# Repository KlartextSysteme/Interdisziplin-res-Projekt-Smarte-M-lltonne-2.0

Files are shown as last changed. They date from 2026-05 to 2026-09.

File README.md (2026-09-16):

# Intelligente Entsorgungssysteme: Smarte Mülltonne 2.0

Software-Repository zum Interdisziplinären Projekt (Prüfungsnummer 2220) im Masterstudiengang Digitale Technologien der Fachhochschule Südwestfalen, Sommersemester 2026.

Team: Alaeddine Baghyour, Jan-Lukas Bellenhaus, S. Fulya Bulut, Theresa Pelz, Jonas Wiesner. Hinweis zur Commit-Historie: Die Commits unter dem Konto Klartext-Systeme stammen von Jonas Wiesner und Jan-Lukas Bellenhaus, die über dasselbe Konto gearbeitet haben. Eine Aufteilung der Beiträge nach Personen ist aus der Historie deshalb nicht ablesbar.

## Was das System tut

Die Smarte Mülltonne fährt selbstständig entlang einer Bodenlinie von ihrem Stellplatz zur Straße und zurück. Ein Raspberry Pi Pico W steuert dabei zwei Schrittmotoren, liest fünf Liniensensoren und mehrere Ultraschallsensoren über einen Multiplexer und misst Füllstand und Akkuspannung. Ein Touchdisplay an der Tonne zeigt Zustand und Diagnosewerte und nimmt lokale Befehle entgegen. Über WLAN meldet sich der Pico bei einer TCP-Bridge auf einem Laptop, die seine Telemetrie an das Backend weiterreicht und Fahrbefehle aus der Kommando-Warteschlange an den Pico zurückgibt. Das Backend (FastAPI, SQLite) verwaltet Tonnen, Füllstände, Sicherheitsereignisse und Routen und bindet einen LLM-Agenten für die Routenplanung an. Die Web-App (Next.js) ist der Leitstand: Flottenliste, Live-Karte, Chat mit dem Agenten, Energie- und Sicherheitspanel sowie Sperren und Steuern einzelner Tonnen.

## Ordnerstruktur

Der gesamte Projektinhalt liegt unter `Smarte Mülltonne/`. Alle Pfade unten sind relativ dazu. Für die Abgabe wurden zwei Ordner umbenannt, `smart-bin` heißt jetzt `Flottenmanagement` und `Test_2` heißt `Hardwaretests`; die Dokumentation verwendet die neuen Namen, siehe Abschnitt „Codeverweise in der Dokumentation". Die Semesterdokumentation und die Abschlusspräsentation sind nicht Teil dieses Repos; sie liegen im Abgabeordner. Der Vorgängerstand (Smarte Mülltonne 1.0, Ordner `Alt/`) und ein früherer Doku-Arbeitsstand wurden für die Abgabe entfernt und sind in der Git-Historie bis Commit `dae74ec9` erhalten.

| Pfad | Inhalt |
|---|---|
| `Software/Quellcode/Client/` | MicroPython-Firmware des Pico W in der Tonne: Fahrlogik, Sensorik, Touchpanel-Oberfläche, TCP-Client zur Bridge. `main.py` startet den Controller. |
| `Software/Quellcode/Client/assets/` | Vorgerenderte Bild-Assets für das Touchdisplay (WF1/RLE-Format). |
| `Software/Quellcode/Server/` | Früher TCP-Server für die Missionssteuerung auf dem Laptop; im Zielsystem übernimmt die Bridge unter `Flottenmanagement/bridge/` diese Rolle. |
| `Software/Flottenmanagement/backend/` | FastAPI-Backend mit Datenmodell, Routern, Agent und Truck-Simulator. |
| `Software/Flottenmanagement/frontend/` | Next.js-Web-App (Leitstand und Admin-Seite). |
| `Software/Flottenmanagement/bridge/` | TCP-Bridge zwischen Pico und Backend sowie ein Pico-Simulator. |
| `Software/Flottenmanagement/simulator/` | Skripte, die Füllstände, Energie, Sicherheitsereignisse und LKW-Fahrt simulieren. |
| `Software/Flottenmanagement/firmware/pico_touchpanel/` | Eigenständige Touchpanel-Firmware mit Kalibrierung, Asset-Werkzeugen und datierten Backups der Display-Stände. |
| `Software/Flottenmanagement/docs/` | Architektur, API-Vertrag, CI-Vorgaben, Handoffs, Design-Specs und Pläne aus der Entwicklung. |
| `Software/Hardwaretests/` | Einzelne Hardware-Testskripte (Motoren, Sensoren, Multiplexer, Display) aus der Inbetriebnahme. |
| `Software/Visualisierungen/` | Architektur- und Zustandsdiagramme, Pinout, Schaltpläne. |
| `Software/Übergabedokument_Smarte_Muelltonne.pdf` | Technisches Übergabedokument zum Client-Server-Quellcode des Pico (Stand April 2026). |

An der Wurzel liegen außerdem `render.yaml` (Deployment-Blueprint für Backend und Web-App auf Render) und `.gitignore`.

## Stand der Dokumentation

Die Semesterdokumentation bezieht sich auf den Branch `route-start-live-akku` im Stand des Commits `c10b40b` vom 11.07.2026. Dieser Commit ist in `main` enthalten. In diesem Stand heißen die Ordner noch `smart-bin` und `Test_2`, und die Ordner `Alt/` sowie `Dokumentation & Präsentation Neu/` sind noch vorhanden. Um genau diesen Stand zu sehen:

```
git checkout c10b40b
```

Zurück zum aktuellen Stand mit `git checkout main`.

## Codeverweise in der Dokumentation

Die Dokumentation zitiert Pfade relativ zu `Smarte Mülltonne/Software/` im Stand `c10b40b`. Nach der Umbenennung für die Abgabe gilt auf `main` die rechte Spalte. Dateien ohne Eintrag in der rechten Spalte haben sich nicht bewegt.

| Pfad in der Dokumentation (Stand `c10b40b`) | Pfad auf `main` |
|---|---|
| `Quellcode/Client/main.py` | unverändert |
| `Quellcode/Client/ui.py` | unverändert |
| `Quellcode/Client/ultraschallsensor.py` | unverändert |
| `Quellcode/Client/global_controller_test.py` | unverändert |
| `Quellcode/Client/multiplexer.py` | unverändert |
| `Quellcode/Client/display.py` | unverändert |
| `Quellcode/Client/touchpanel.py` | unverändert |
| `Quellcode/Client/wireframe.py` | unverändert |
| `Quellcode/Client/assets/` | unverändert |
| `smart-bin/backend/config.py` | `Flottenmanagement/backend/config.py` |
| `smart-bin/backend/agent/planner.py` | `Flottenmanagement/backend/agent/planner.py` |
| `smart-bin/backend/agent/tools.py` | `Flottenmanagement/backend/agent/tools.py` |
| `smart-bin/backend/routers/admin_demo.py` | `Flottenmanagement/backend/routers/admin_demo.py` |
| `smart-bin/backend/routers/bins.py` | `Flottenmanagement/backend/routers/bins.py` |
| `smart-bin/backend/routers/commands.py` | `Flottenmanagement/backend/routers/commands.py` |
| `smart-bin/backend/routers/routes.py` | `Flottenmanagement/backend/routers/routes.py` |
| `smart-bin/backend/routers/ws.py` | `Flottenmanagement/backend/routers/ws.py` |
| `smart-bin/frontend/app/admin/page.tsx` | `Flottenmanagement/frontend/app/admin/page.tsx` |
| `smart-bin/frontend/app/dashboard/components/OperatorTour.tsx` | `Flottenmanagement/frontend/app/dashboard/components/OperatorTour.tsx` |
| `smart-bin/firmware/pico_touchpanel/touch_calibrate.py` | `Flottenmanagement/firmware/pico_touchpanel/touch_calibrate.py` |
| `smart-bin/firmware/pico_touchpanel/tools/png_to_wf1.py` | `Flottenmanagement/firmware/pico_touchpanel/tools/png_to_wf1.py` |
| `smart-bin/firmware/pico_touchpanel/backups/2026-06-11_light_mode_before_icon_shape_fix/` | `Flottenmanagement/firmware/pico_touchpanel/backups/2026-06-11_light_mode_before_icon_shape_fix/` |
| `smart-bin/docs/api_contract.md` | `Flottenmanagement/docs/api_contract.md` |
| `smart-bin/docs/ci_farben_typografie.md` | `Flottenmanagement/docs/ci_farben_typografie.md` |
| `smart-bin/docs/handoff_fahrlogik_2026-06-27.md` | `Flottenmanagement/docs/handoff_fahrlogik_2026-06-27.md` |
| `smart-bin/docs/touchpanel_tonnenicon_design_notes.md` | `Flottenmanagement/docs/touchpanel_tonnenicon_design_notes.md` |
| `smart-bin/docs/superpowers/plans/2026-07-04-hardware-test-followup.md` | `Flottenmanagement/docs/superpowers/plans/2026-07-04-hardware-test-followup.md` |
| `smart-bin/docs/superpowers/specs/2026-07-04-hardware-test-followup-design.md` | `Flottenmanagement/docs/superpowers/specs/2026-07-04-hardware-test-followup-design.md` |

Die gestalterischen Vorgaben für die Web-App (Farben, Ampelfarben, Schrift, Layout) stehen in `Flottenmanagement/docs/ci_farben_typografie.md`. Die Design-Spezifikationen der Agenten-Aufträge folgen dem Namensschema `<thema>-design.md` in `Flottenmanagement/docs/`.

## Starten

Backend (Python 3.12, aus `Smarte Mülltonne/Software/Flottenmanagement/backend/`):

```
pip install -r requirements.txt
cp .env.example .env
uvicorn main:app --host 0.0.0.0 --port 8000
```

In `.env` werden Admin-Token, `GROQ_API_KEY` für den Agenten, erlaubte CORS-Origins und die Depot-Koordinaten gesetzt. Die Datenbank `smart_bin.db` wird beim ersten Start angelegt.

Web-App (Node 22, aus `Smarte Mülltonne/Software/Flottenmanagement/frontend/`):

```
npm ci
npm run dev
```

Die App läuft dann auf Port 3000 und erwartet das Backend unter `NEXT_PUBLIC_API_URL` (Standard im Deployment: `http://localhost:8000`) und den Live-Kanal unter `NEXT_PUBLIC_WS_URL` (`ws://localhost:8000/ws/live`). `npm run build` erzeugt den statischen Export nach `out/`.

Bridge zur Tonne (aus `Smarte Mülltonne/Software/Flottenmanagement/`):

```
python bridge/tcp_bridge.py --bin-id 1 --backend http://localhost:8000
```

Der Pico verbindet sich mit `BRIDGE_HOST` und `BRIDGE_PORT` (50002) aus `Quellcode/Client/config.py`. Ohne Hardware lässt sich der Pico mit `bridge/pico_tcp_simulator.py` nachstellen; die Skripte in `simulator/` erzeugen Füllstands-, Energie- und Sicherheitsdaten gegen das laufende Backend.

Pico-Firmware: Die Dateien aus `Quellcode/Client/` einschließlich `assets/` auf den Pico W kopieren; `main.py` startet beim Booten den Controller. WLAN-Zugang und Bridge-Adresse stehen in `config.py`.

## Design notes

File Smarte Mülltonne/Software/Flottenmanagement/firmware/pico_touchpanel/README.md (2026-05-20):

# Pico Touchpanel Firmware

MicroPython firmware draft for the smart-bin touch display.

## Hardware

- Raspberry Pi Pico W
- ILI9341 2.8 inch SPI display
- Target UI: landscape `320 x 240`

Known working display wiring from the first hardware test:

| Signal | Pico GPIO |
|---|---:|
| SCK | GP18 |
| MOSI | GP19 |
| CS | GP17 |
| DC | GP20 |
| RST | GP21 |

## Files

- `main.py` starts the UI.
- `display.py` contains the minimal ILI9341 drawing driver.
- `ui.py` contains the screen state machine and wireframe implementation.
- `config.py` contains pins, display rotation and backend placeholders.

## First Test

Copy all `.py` files to the Pico W and run `main.py`.

If the UI is rotated or mirrored, change `DISPLAY_ROTATION` in `config.py`.
Likely values to try: `0x28`, `0x48`, `0x88`, `0xE8`.

Touch is not connected yet in this draft. For a first screen test, call
`ui.handle_touch(x, y)` from the REPL after `main.py` has drawn the UI.

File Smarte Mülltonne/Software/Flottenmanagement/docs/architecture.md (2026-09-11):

# Smarte Mülltonne 2.0 — Architektur-Dokumentation

> **Projekt:** FH SWF Digitale Technologien, interdisziplinär
> **Software-Lead:** Jonas Wiesner (Backend, LLM-Agent, Dashboard)
> **Hardware-Lead:** Mech-Team (Antrieb, Sensorik, Tonne-Bau)
> **Stand:** Mai 2026
> **Scope:** Software-Komponenten unter `Flottenmanagement/` — Backend, Frontend, Simulatoren, Agent, Pico-W-Touchpanel-Konzept

> **Aktueller Agent-Handoff:** siehe `docs/handoff_2026-06-12.md` fuer den
> neuesten Stand nach Render-Deployment, Groq-Umstellung, Solar-Entfernung aus
> der UI und die bekannte Truck-Depot-Routing-Baustelle.

---

## 1. System-Überblick

Die Smarte Mülltonne 2.0 ist ein Hardware-/Software-Verbundsystem aus autonomen Mülltonnen, einem Sammelfahrzeug und einer zentralen Flottenmanagement-Plattform. Diese Doku beschreibt ausschließlich die **Software-Schicht**. Die Mechanik (Antrieb, Fahrwerk, Sensor-Integration) wird parallel vom Mech-Team gebaut und ist hier nur als API-Schnittstelle relevant.

### 1.1 Komponenten-Diagramm

```
┌──────────────────────────────────────────────────────────────────────────┐
│                          Smarte Mülltonne 2.0                            │
│                                                                          │
│  ┌─────────────────┐    HTTP / SSE    ┌──────────────────────────────┐  │
│  │   Frontend      │ ←─────────────→  │  Backend (FastAPI)           │  │
│  │   (Next.js 15)  │   WebSocket      │                              │  │
│  │                 │ ←─────────────→  │  ┌─────────┐  ┌──────────┐   │  │
│  │  • Dashboard    │                  │  │ SQLite  │  │ Routing  │   │  │
│  │  • Map (Leaflet)│                  │  │  (DB)   │  │ (OSRM)   │   │  │
│  │  • Chat (SSE)   │                  │  └─────────┘  └──────────┘   │  │
│  │  • Sim-Controls │                  │                              │  │
│  └─────────────────┘                  │  ┌──────────────────────┐    │  │
│                                       │  │ LangChain Agent      │    │  │
│                                       │  │  ↳ Groq Llama 3.3    │    │  │
│                                       │  └──────────────────────┘    │  │
│                                       └────────┬─────────────────────┘  │
│                                                │                        │
│                            HTTP polling (2s)   │                        │
│                  ┌─────────────────────────────┼──────────────────────┐ │
│                  ▼                             ▼                      ▼ │
│         ┌────────────────┐         ┌────────────────┐      ┌──────────┐ │
│         │  mock_truck    │         │  mock_bins     │      │ Pico W   │ │
│         │  (Python sim)  │         │  (Python sim)  │      │ Tonne(n) │ │
│         │                │         │                │      │ (geplant)│ │
│         └────────────────┘         └────────────────┘      └──────────┘ │
└──────────────────────────────────────────────────────────────────────────┘
```

### 1.2 Tech-Stack

| Schicht | Technologie | Begründung |
|---|---|---|
| Frontend | Next.js 15 (App Router) + React 19 + TypeScript + Tailwind v4 | SSR-fähig, moderne Hooks, kleines Setup für Single-Page-Dashboard |
| Karten | Leaflet + react-leaflet 5 + OpenStreetMap-Tiles | Kein API-Key, freie Karten |
| Backend | FastAPI + Pydantic + SQLAlchemy 2.0 | Async-first, OpenAPI auto-doc, gute DX |
| Datenbank | SQLite | Single-Node-Demo, kein Server, später durch Postgres tauschbar (URL-Tausch) |
| Routing | OSRM Public Demo + python-tsp | Echte Straßen-Routen, Open-Source-TSP-Heuristiken |
| Agent | LangChain 1.x + LangGraph + Groq (Llama 3.3 70B) | Tool-Calling, Free-Tier ausreichend für Demo |
| Realtime | FastAPI WebSocket (Live-Daten) + SSE (Chat-Stream) | Bidirektional für Telemetrie, unidirektional für Token-Streaming |
| Tonne-Hardware | Raspberry Pi Pico W + ILI9341 + XPT2046 | MicroPython, WLAN nativ, günstig, ausreichende Performance für UI |

---

## 2. Repo-Struktur

```
Flottenmanagement/
├── backend/
│   ├── main.py                  # FastAPI-Entry, Router-Registrierung, CORS
│   ├── config.py                # Pydantic-Settings (.env-Loader)
│   ├── database.py              # SQLAlchemy-Engine + Seed-Daten (35 Tonnen)
│   ├── models/
│   │   ├── bin.py               # Bin-ORM
│   │   ├── route.py             # Route-ORM (waypoints, geometry, distances)
│   │   ├── event.py             # SecurityEvent-ORM
│   │   └── command.py           # Command-Queue für Hardware
│   ├── routers/
│   │   ├── bins.py              # GET /bins, POST /bins/{id}/update
│   │   ├── routes.py            # POST /routes/plan (NN + 2-opt + Held-Karp)
│   │   ├── security.py          # Events, lock/unlock
│   │   ├── energy.py            # Akku- und Solar-Status
│   │   ├── truck.py             # Truck-Position + -Command-Endpoints
│   │   ├── commands.py          # Pull-Queue für Hardware (Pico W)
│   │   ├── agent.py             # POST /agent/chat (SSE)
│   │   ├── sim.py               # GET/PUT /sim/speed (Speed + Pause)
│   │   └── ws.py                # WebSocket /ws/live
│   ├── services/
│   │   └── routing.py           # OSRM-Client (echte Straßen-Geometrie)
│   ├── agent/
│   │   ├── planner.py           # ChatGroq + create_agent (LangGraph)
│   │   ├── prompts.py           # System-Prompt für den Disponenten-Agent
│   │   └── tools.py             # Tool-Definitionen (9 Tools)
│   └── scripts/
│       ├── geocode_bins.py      # Nominatim-Batch-Geocoder
│       └── tsp_benchmark.py     # NN vs 2-opt vs Held-Karp
│
├── frontend/
│   ├── app/dashboard/
│   │   ├── page.tsx             # Hauptseite: Header + 3-Spalten-Layout
│   │   └── components/
│   │       ├── LeafletMap.tsx   # Karte mit AnimatedTruckMarker
│   │       ├── FleetPanel.tsx   # Linke Spalte: Tonnen-Liste
│   │       ├── ChatInterface.tsx# Rechte Spalte: SSE-Stream + Tool-Cards
│   │       ├── EnergyPanel.tsx
│   │       ├── SecurityPanel.tsx
│   │       └── AlertBanner.tsx
│   ├── lib/
│   │   ├── api.ts               # REST-Wrapper + streamChat (SSE)
│   │   └── useWebSocket.ts      # Live-Data-Hook
│   └── types/index.ts           # Bin, Route, ChatMessage, ToolCall, ...
│
├── simulator/
│   ├── mock_truck.py            # Fahrt entlang OSRM-Geometrie
│   ├── mock_bins.py             # Füllstand-Drift
│   ├── mock_energy.py           # Solar/Akku-Simulation
│   └── mock_security.py         # Sicherheitsereignisse
│
└── docs/
    ├── architecture.md          # ← dieses Dokument
    └── api_contract.md          # API-Vertrag für Pico-W-Firmware
```

---

## 3. Datenmodell

### 3.1 Bin (Mülltonne)

| Feld | Typ | Beschreibung |
|---|---|---|
| `id` | int (PK) | Eindeutige ID |
| `name` | str | Anzeigename („Westfalenweg 3") |
| `address` | str | Vollständige Adresse |
| `lat` / `lng` | float | Koordinaten (Nominatim geocodiert) |
| `fill_level` | int (0–100) | Aktueller Füllstand in Prozent |
| `battery` | int (0–100) | Akkustand |
| `solar_output_w` | float | Solar-Leistung in Watt |
| `is_charging` | bool | Lädt aktuell? |
| `status` | str | `idle` / `in_use` / `emptied` |
| `locked` | bool | Aus Sicherheits-/Wartungsgründen gesperrt |
| `last_seen` | datetime | Letzter Status-Update |

### 3.2 Route

| Feld | Typ | Beschreibung |
|---|---|---|
| `id` | int (PK) | Eindeutige ID |
| `created_at` | datetime | Plan-Zeitpunkt |
| `waypoints` | list[int] | Bin-IDs in der finalen 2-opt-Reihenfolge |
| `distance_m` | int | OSRM-Strecke (echte Straßen) |
| `duration_s` | int? | OSRM-Fahrzeit |
| `geometry` | dict | GeoJSON LineString der Tour |
| `nn_distance_m` | int? | NN-Baseline (planar, für A/B) |
| `optimized_distance_m` | int? | 2-opt-Distanz (planar) |
| `exact_distance_m` | int? | Held-Karp-Optimum (planar, nur n ≤ 15) |
| `completed` | bool | Tour abgeschlossen? |
| `llm_reasoning` | str? | Optional: Agent-Begründung |

### 3.3 SecurityEvent

| Feld | Typ | Beschreibung |
|---|---|---|
| `id`, `bin_id`, `created_at` | – | Standard |
| `event_type` | str | `tamper`, `vandalism`, `user_report`, `fire`, ... |
| `reason` | str? | Freitext-Beschreibung |
| `resolved` | bool | Quittiert? |

### 3.4 Command (Hardware-Queue)

| Feld | Typ | Beschreibung |
|---|---|---|
| `id`, `bin_id`, `created_at` | – | Standard |
| `action` | str | `lock`, `unlock`, `open_lid`, `beep` |
| `payload` | dict? | Optionale Parameter |
| `acked` | bool | Von der Hardware bestätigt? |

**Sync-Pattern:** Hardware pollt `GET /bins/{id}/pending-command` alle 2 s, führt aus, sendet `POST /bins/{id}/ack`.

---

## 4. API-Endpoints

| Methode | Pfad | Zweck |
|---|---|---|
| GET | `/health` | Healthcheck |
| GET | `/config/public` | Depot-Koordinaten, App-Konstanten |
| GET | `/bins` | Alle Tonnen |
| POST | `/bins/{id}/update` | Sensor-Update (fill, battery, status) |
| POST | `/bins/{id}/command` | Befehl in Hardware-Queue legen |
| GET | `/bins/{id}/pending-command` | Pull-Endpoint für Pico |
| POST | `/bins/{id}/ack` | Command-Ack vom Pico |
| POST | `/routes/plan` | Route planen (NN + 2-opt + Held-Karp ≤ 15) |
| GET | `/routes/latest` | Neueste Route |
| POST | `/routes/{id}/complete` | Tour abschließen |
| GET | `/truck/status` | Truck-Position + Action |
| POST | `/truck/position` | Position vom Simulator |
| POST | `/truck/command` | Truck steuern (`start`/`pause`/`stop`) |
| GET | `/security/events` | Offene Sicherheitsmeldungen |
| POST | `/security/events` | Neues Event anlegen |
| POST | `/security/{id}/lock` | Tonne sperren (Admin-Token) |
| POST | `/security/{id}/unlock` | Tonne entsperren |
| GET | `/energy` | Akku- und Solar-Status aller Tonnen |
| GET | `/sim/speed` | Sim-Speed + Pause-State |
| PUT | `/sim/speed` | Sim-Speed setzen / Pause toggeln |
| POST | `/agent/chat` | SSE-Chat-Stream |
| WS | `/ws/live` | Bins + Truck + Alerts alle 2 s |

---

## 5. Architektur-Entscheidungen (ADRs)

Die wichtigsten Entscheidungen im Entwicklungsprozess — mit Begründung für künftige Maintainer.

### ADR-1 — SQLite statt Supabase/PostgreSQL

**Kontext:** Demo mit 35 Tonnen, Single-Node, kein Multi-User.
**Entscheidung:** SQLite via SQLAlchemy.
**Begründung:** Setup-Zeit ~ 0 s, keine externen Dependencies, file-based. Migration zu PostgreSQL ist später ein URL-Tausch. Supabase wäre nur sinnvoll bei Multi-User-Auth, Production-Deployment oder Echtzeit-Replikation — nichts davon im Scope.

### ADR-2 — Statische Bin-Adressen statt GPS

**Kontext:** Mülltonnen sind ortsfest.
**Entscheidung:** Koordinaten einmalig via Nominatim geocodiert, in DB gespeichert.
**Begründung:** Spart GPS-Modul auf der Hardware, vereinfacht Pico-Firmware, Standorte sind bekannt. Konsequenz: Hardware sendet nur Status (Füllstand, Akku, Sicherheit), keine Position.

### ADR-3 — Pull-basierte Command-Queue für Hardware

**Kontext:** Pico W ist Microcontroller — kann nicht als Server angesprochen werden.
**Entscheidung:** Pico pollt alle 2 s `GET /bins/{id}/pending-command`. Backend ist nie der Initiator.
**Begründung:**
- Funktioniert ohne öffentliche IP/Port-Forwarding auf der Tonne
- Einfach zu debuggen
- Tolerant gegenüber kurzen Netzausfällen
- Latenz ≤ 2 s ist für Sperren völlig ausreichend

### ADR-4 — OSRM Public Demo statt Self-Hosting

**Kontext:** Brauchen Straßen-Routing.
**Entscheidung:** `https://router.project-osrm.org` als Free-Service.
**Begründung:** Keine Auth, kein Hosting-Aufwand. Fallback auf Haversine ist eingebaut, falls OSRM nicht erreichbar. Für Production müsste eigenes OSRM aufgesetzt werden.

### ADR-5 — LLM als Dispatch-Interface, NICHT als Entscheider

**Kontext:** Hellweg-Feedback (April 2026): „Akku-Reaktionen und Routenplanung lassen sich ohne LLM lösen — wozu der Aufwand?"

**Entscheidung:** Das LLM trifft **keine algorithmischen Entscheidungen**. Routing, Schwellwerte, Lock-Regeln sind deterministischer Python-Code. Das LLM übersetzt nur Natursprache in Tool-Calls.

```
User: "Sperre Tonne 3 wegen Vandalismus"
  → LLM ruft: lock_bin(bin_id=3, reason="Vandalismus")
  → Python-Code in routers/security.py legt Command in Queue
  → Pico W pollt, führt Motor-Befehl aus
```

**Vorteile:**
- Volle Kontrolle über Entscheidungslogik (auditierbar)
- Keine Halluzinationen bei Zahlen (Tools liefern reale DB-Daten)
- LLM-Ausfall macht Dashboard nicht unbenutzbar (Frontend hat eigene Buttons)
- Chat ist additiv — kein kritischer Pfad

### ADR-6 — Groq + Llama 3.3 70B statt Anthropic Claude

**Kontext:** Anthropic-Account ohne Guthaben.
**Entscheidung:** Groq Free-Tier mit Llama 3.3 70B (Tool-Calling-fähig).
**Begründung:** 0 € Kosten, schnelle Inferenz (Groq LPU ~ 500 tok/s), `langchain-groq` als Drop-in, Tool-Calling-Qualität ausreichend. Wechsel zu Anthropic später ist 3 Code-Zeilen.

### ADR-7 — 2-opt seeded mit Nearest-Neighbour

**Kontext:** Initial nur NN-Sortierung nach Füllstand → 32 km Route bei 13 Tonnen.
**Trigger:** Hellweg-Feedback: „k-opt findet bessere Lösungen, NN hat pathologische Fälle."

**Entscheidung:** `python-tsp` als Dependency, 2-opt local search seeded mit NN-Lösung. Für n ≤ 15 zusätzlich Held-Karp-DP als Optimum-Referenz.

**Begründung:** 2-opt garantiert ≤ NN-Distanz, läuft in < 1 s bei n=18. Held-Karp dient nur als Verifikation und ist bei n > 15 zu langsam für interaktive Nutzung.

**Messung (35-Tonnen-Demo):**
- NN-Baseline: 9,11 km (planar)
- 2-opt: 8,19 km (planar, −10,1 %)
- OSRM real-street: 16,8 km → 15,2 km nach Optimierung

### ADR-8 — Füllstand-Threshold (60 %)

**Kontext:** Bei 35 Tonnen wäre eine „alle abfahren"-Route unsinnig lang.
**Entscheidung:** Nur Tonnen mit `fill_level >= 60 %` und `locked == False` werden in der Tour geplant.
**Begründung:** Entspricht der Agent-Regel „Tonnen < 30 % lohnen sich selten", spart Strecke, Schwelle ist Konstante in `routes.py`.

### ADR-9 — SSE für Chat-Streaming statt WebSocket

**Kontext:** Token-by-Token-Streaming vom Agent.
**Entscheidung:** Server-Sent Events.
**Begründung:** Chat ist unidirektional, SSE läuft über normales HTTP ohne Upgrade-Handshake, LangChain liefert via `astream_events()`. WebSocket bleibt für bidirektionalen Live-Feed (Bins + Truck + Alerts).

### ADR-10 — Frontend-Marker-Smoothing via requestAnimationFrame

**Kontext:** Truck-Position kommt alle 1–2 s vom WebSocket — Marker „springt".
**Entscheidung:** `AnimatedTruckMarker` interpoliert per RAF zwischen alter und neuer Position über 1,5 s.
**Begründung:** Vermeidet Teleport-Effekt. Logik bleibt im Frontend, keine Server-Last.

### ADR-11 — Sim-Speed-Cap auf 20×

**Kontext:** Initial wollten wir 50×. Bei 20× brachen Bin-Refill und Truck-Pickup zusammen.
**Entscheidung:** Maximum 20×, Bin-Refill-Increment sublinear gedeckelt (`min(speed, 5)`).
**Begründung:**
- 50× hätte Tonnen so schnell befüllt, wie der Truck sie leeren konnte
- Truck-Proximity-Check musste **innerhalb** der `advance()`-Schleife passieren, sonst überspringt der Truck Tonnen
- Sublineare Skalierung hält das System auch unter Last leerbar

### ADR-12 — Tonnen-Display ist separate Anwender-Schnittstelle

**Kontext:** Frage: „soll das Display dasselbe sein wie das Dashboard?"
**Entscheidung:** Nein. Display am Pico W ist für **Anwohner und Wartung**, nicht für den Fleet-Operator.
**Begründung:** Drei verschiedene Zielgruppen, drei verschiedene UX-Paradigmen:
- Dashboard → Stefan Krüger (Fahrer/Disponent), 3-Spalten-Layout, viele Daten
- Touch-Display → Anwohner, 5 Screens, 320 × 240, Handschuh-tauglich
- Touch-Display (Wartung) → Service-Techniker, PIN-geschützt, Diagnose-Daten

Backend-API ist für beide identisch — Endpoints werden geteilt.

### ADR-13 — Pico W (RP2040) statt Raspberry Pi 4

**Kontext:** Mech-Team setzt auf Pico W.
**Entscheidung:** Firmware in MicroPython, kein Linux-Stack.
**Begründung:**
- Pico W ~ 7 €, Pi 4 ~ 50 € — bei vielen Tonnen relevant
- Keine OS-Updates, keine Boot-Zeiten, sofort betriebsbereit
- 264 KB RAM reicht für UI + HTTP-Polling
- WLAN nativ über CYW43439
- Konsequenz: Firmware ist **eine MicroPython-Mainloop** (Sensoren, Commands, UI in einem Prozess), nicht mehrere systemd-Services

---

## 6. Schlüssel-Algorithmen

### 6.1 Tour-Planung (`backend/routers/routes.py`)

```
Input:  Tonnen mit fill_level ≥ 60 %, nicht gesperrt
Output: Geordnete Bin-IDs + OSRM-Geometrie + Distanz-Metriken

  1. Filtere Tonnen nach Threshold und lock-Status
  2. Baue (n+1)×(n+1) planare Distanzmatrix (Depot = Knoten 0)
  3. Nearest-Neighbour als Baseline       → nn_distance (Persistenz für A/B)
  4. 2-opt local search seeded mit NN     → opt_distance, opt_perm
  5. Wenn n ≤ 15: Held-Karp-DP            → exact_distance (Optimum-Referenz)
  6. OSRM-Call mit opt_perm               → reale Straßen-Geometrie
  7. Persistiere Route mit allen drei Distanz-Metriken
```

**Performance bei n=18:** ~ 230 ms gesamt (davon OSRM ~ 150 ms, 2-opt < 100 ms).

### 6.2 Truck-Simulation (`simulator/mock_truck.py`)

Walking-Algorithmus entlang OSRM-Geometrie mit Speed-Multiplikator,
integrierter Proximity-Prüfung und realistisch begrenzter Ladekapazität:

```python
load_units = 0

while seg_index < len(coords) - 1:
    speed, paused = await get_sim_state()
    if paused:
        await sleep(0.5); continue

    budget_m = SPEED_MPS * TICK_S * speed   # Meter pro Tick

    # Walk along geometry, checking proximity at EACH segment endpoint
    pos, seg_index, hit_bin = advance_with_arrival_check(...)

    if hit_bin:
        waste_units = get_bin_fill(hit_bin)
        if load_units + waste_units > TRUCK_CAPACITY_UNITS:
            drive_to_depot(); unload(); load_units = 0

        collected = empty_bin(hit_bin)
        load_units += collected
        visited.add(hit_bin)
    await sleep(TICK_S)
```

**Key-Insight (ADR-11):** Proximity-Check muss **innerhalb** der `advance`-Loop laufen, sonst überspringt der Truck Tonnen bei hoher Speed.

**Kapazitätsmodell:** Eine 100%-Tonne entspricht 100 Ladeeinheiten. Der
Demo-Truck fasst 600 Einheiten, also grob sechs volle Tonnen. Wenn ein weiterer
Pickup die Kapazität überschreiten würde, fährt der Truck zum Depot, setzt
`action="returning_full"`, entlädt mit `action="unloading"` und nimmt die Route
danach wieder auf. Das ist der erste Schritt Richtung Mehrfahrzeug-Logik:
Später kann ein Dispatcher verbleibende Waypoints auf weitere Trucks verteilen,
statt denselben Truck Zwischenfahrten machen zu lassen.

### 6.3 Bin-Refill-Simulation (`simulator/mock_bins.py`)

```python
increment = random.uniform(0, 2) * min(speed, 5)   # sublinear gedeckelt
sleep    = max(0.5, 10.0 / speed)                  # Floor 0,5 s
```

**Warum sublinear:** Lineare Skalierung würde bei 20× zu 80 %/s führen — Truck-Pickup käme nicht hinterher.

---

## 7. Frontend-Architektur

### 7.1 Layout-Prinzip: 3-Spalten-Dashboard

```
┌──────────────────────────────────────────────────────────────┐
│  Header: Logo | Sim-Controls | Route-Info | Live-Badge       │
├─────────────┬──────────────────────────────┬─────────────────┤
│             │                              │  Tab-Switcher   │
│  Fleet      │                              │  (Chat/Energie/ │
│  Panel      │         Leaflet-Karte        │   Security)     │
│  (Liste)    │  (Bins + Truck + Route +     │                 │
│             │   Depot)                     │  Active Tab     │
│  35 Tonnen  │                              │  Content        │
│  sortiert   │                              │                 │
│  nach Fill  │                              │                 │
└─────────────┴──────────────────────────────┴─────────────────┘
```

Begründet durch User-Persona **Stefan Krüger** (Fahrer und Disponent in Personalunion): Statusübersicht + Räumlichkeit + Aktion gleichzeitig sichtbar, keine Tab-Wechsel für die häufigsten Aufgaben. Detail siehe Doku-Kapitel „Zielgruppe und User Persona".

### 7.2 Datenfluss

```
WebSocket /ws/live (2s)
  ↓
useLiveData() hook
  ↓
DashboardPage state: { bins, alerts, truck }
  ↓
Pass-through props an FleetPanel + LeafletMap + AlertBanner

REST polling /routes/latest (10s)
  ↓
activeRoute state → LeafletMap (Polyline) + Header (Route-Info)

SSE /agent/chat
  ↓
ChatInterface streamChat() callback
  ↓
messages state (lokal, nicht persistiert)
```

### 7.3 Sim-Controls

Header-Element zur Live-Steuerung der Simulation:

- **Play/Pause-Toggle:** Friert alle Simulatoren ein (`sim.paused=True`). Truck postet `action="paused"`, Bins drift en stoppt.
- **Speed-Buttons:** `1× / 5× / 10× / 20×`. Truck-Bewegung und Bin-Refill skalieren entsprechend.
- Bei Pause sind Speed-Buttons disabled (ausgegraut).

### 7.4 Chat-Tool-Transparenz

Der Agent macht Tool-Calls (z.B. `get_bins`, `plan_route`) sichtbar als klappbare Karten im Chat. Bewusst:
- User sieht **was** der Agent tut, nicht nur das Ergebnis
- Hilft Vertrauen aufbauen („kein magischer Output, sondern reproduzierbare Schritte")
- Beim Debuggen: Input/Output jedes Tools sichtbar

---

## 8. Touchpanel-Konzept (Pico W)

### 8.1 Hardware

- **MCU:** Raspberry Pi Pico W (RP2040 + CYW43439 WLAN)
- **Display:** 2,8" ILI9341 SPI, 320 × 240 px
- **Touch:** XPT2046 resistiv (4-Wire)
- **Verbindung:** Shared SPI0-Bus mit separaten CS-Pins

### 8.2 Firmware-Architektur

**Eine** MicroPython-Mainloop mit drei async-Tasks (`uasyncio`):

```python
async def main():
    await uasyncio.gather(
        sensor_loop(),    # Füllstand/Akku alle 8 s posten
        command_loop(),   # Command-Queue pollen, lock/unlock anwenden
        ui_loop(),        # Touch-Events verarbeiten, Display rendern
    )
```

State teilt sich über das `UI`-Objekt — keine IPC nötig (single-threaded cooperative async).

### 8.3 Sync-Pattern

| Richtung | Wer initiiert? | Latenz | Beispiel |
|---|---|---|---|
| Sensor → Backend | Pico (~ 8 s) | – | `POST /bins/{id}/update` mit fill_level |
| Backend → Pico | Pico pollt (~ 2 s) | ≤ 2 s | Dashboard sperrt → `lock`-Command in Queue → Pico holt |
| User → Backend | Pico (sofort bei Tap) | – | „Problem melden" → `POST /security/events` |

**Lokale Aktionen bleiben lokal:** „Klappe öffnen" geht direkt an Servo-GPIO, nicht übers Backend. Backend wird nur informiert (`status=in_use`).

### 8.4 UX

5 Pflicht-Screens:
1. **IDLE** — Füllstand + Hauptbutton
2. **Hauptmenü** — Klappe öffnen / Problem melden / Wartung
3. **Problem melden** — Beschädigt / Geruch / Zurück
4. **Gesperrt** — Vollbild-Hinweis
5. **Wartung mit PIN** — 3×4 Zahlenpad

Designprinzipien:
- **≥ 60 × 60 px Touch-Targets** (resistiv + Handschuhe)
- Keine Swipe-Gesten (resistiv unzuverlässig)
- Hoher Kontrast (Sonneneinstrahlung)
- Bitmap-Fonts statt TTF (RAM/Performance)

---

## 9. Demo-Setup

### 9.1 Vorab

`.env` im `backend/`:

```bash
DATABASE_URL=sqlite:///./smart_bin.db
ADMIN_TOKEN=changeme
GROQ_API_KEY=gsk_...
CORS_ORIGINS=["http://localhost:3000"]
```

### 9.2 Hochfahren

```bash
# Backend (Port 8000)
cd backend
.venv/bin/uvicorn main:app --port 8000

# Simulatoren (in zwei Terminals oder nohup)
cd simulator
python mock_truck.py
python mock_bins.py

# Frontend (Port 3000)
cd frontend
npm run dev
```

→ Dashboard: <http://localhost:3000>
→ Swagger: <http://localhost:8000/docs>

### 9.3 Demo-Daten

- **35 Tonnen** in 4 Clustern um die FH Soest (Westfalenweg, Kasernenweg, Elsa-Brandström, Siegener Str.) + FH Campus
- **Cluster-Größe:** 700 × 600 m
- **Depot:** Doyenweg 21
- **Fill-Verteilung deterministisch** (`random.seed(42)`): 6 kritisch / 10 hoch / 12 mittel / 7 niedrig

### 9.4 Demo-Flow (3-Minuten-Pitch)

1. Dashboard zeigt 35 smarte Tonnen, color-coded nach Füllstand
2. „Route planen" → 2-opt-Optimierung läuft, Badge zeigt Ersparnis
3. Sim-Speed 5× — Truck fährt los, leert die kritischen Tonnen
4. Im Chat: „Sperre Tonne X" → Agent ruft Tool, Dashboard reagiert sofort
5. WebSocket-Banner für Sicherheitsereignisse

---

## 10. Lessons Learned

Erfahrungen aus der Entwicklung, relevant für Maintainer und Folge-Teams.

### 10.1 Nominatim-Geocoding ist unzuverlässig

15 von 50 versuchten Adressen waren in OSM nicht erfasst (Christian-Rohlfs-Straße, Im Tabaksgang, Dammweg in 59494 Soest existieren nicht in OpenStreetMap, obwohl real). Konsequenzen:
- Adressen **vorher** prüfen, nicht erst nach dem Geocoding
- Strukturierte Queries (`street=...&city=...`) liefern bessere Treffer als Freitext
- Bei Duplikaten (mehrere Hausnummern auf der gleichen Straßenmitte): deterministischer Jitter pro Hausnummer-Hash für visuelle Trennung auf der Karte

### 10.2 Pydantic-Settings respektiert Shell-Env

Eine leere `ANTHROPIC_API_KEY=""` Shell-Variable überschrieb den Wert aus `.env`. Schwer zu debuggen, weil das Env-File äußerlich korrekt aussieht. Fix: vor Start `unset ANTHROPIC_API_KEY` oder bewusst `model_config = SettingsConfigDict(env_file=".env", ...)` in Pydantic V2.

### 10.3 LangChain 1.x bricht die 0.x-API

`AgentExecutor` und `create_tool_calling_agent` sind in LangChain 1.x entfernt. Ersatz: `create_agent` aus `langchain.agents` (LangGraph-basiert). Auch das Input-Format wechselt von `{"input": ..., "chat_history": [...]}` zu `{"messages": [...]}`. Bei Migration **beides** anpassen, nicht nur den Import.

### 10.4 Groq lehnt leere Tool-Returns ab

Ein Tool, das `[]` zurückgibt, wird von LangChain als ToolMessage mit Content `[]` weitergereicht. Groq lehnt das mit HTTP 400 ab (`content : value must be a string OR minimum number of items is 1`). Fix: Alle Tools liefern garantiert einen **nicht-leeren String** (JSON-encoded oder Klartext-Fallback bei leerem Ergebnis).

### 10.5 Sim-Speed ist ein verstecktes Race-Condition-Problem

Bei 20× füllen Bins schneller, als der Truck leeren kann. Bei großen Tick-Sprüngen (160 m/Tick) verpasst der Truck Tonnen, deren Stop-Zone (35 m) innerhalb eines Ticks komplett überfahren wird. Beide Bugs nur unter Last sichtbar. Lehre: **Skalierungs-Effekte immer im integrierten System testen**, nicht in der Komponente isoliert.

### 10.6 Dashboard ohne Marker-Interpolation wirkt billig

Roher WebSocket-Stream → Marker springt alle 2 s um 10–20 px. Wirkt amateurhaft im Demo. RAF-Interpolation für 1,5 s zwischen Updates rettet das visuelle Erlebnis ohne Server-Änderung.

### 10.7 Reverse-Engineering der UX wegen Code-First-Ansatz

Dashboard und Touchpanel-Konzept wurden **vor** den Wireframes implementiert. Konsequenz: jetzt müssen nachträglich Wireframes erstellt werden (Fulya-Briefing), damit die Doku methodisch sauber bleibt. Lehre: bei Folgeprojekten Wireframes **vor** Code, auch bei „nur" einem Prototyp.

### 10.8 Hellweg-Feedback war ein Architektur-Geschenk

Sein Einwand „warum LLM für deterministische Aufgaben?" hat die LLM-Rolle scharf gemacht — nicht als Entscheider, sondern als natürlichsprachliche Übersetzung in Tool-Calls. Das ist fachlich der einzig vertretbare LLM-Einsatz in einem solchen System.

---

## 11. Bekannte Limitierungen und Future Work

| Thema | Status | Nächste Schritte |
|---|---|---|
| Hardware-Integration (Pico W) | Konzept fertig, Firmware-Skelett vorhanden | Mech-Team integriert Sensorik + Motor; Firmware flashen |
| Held-Karp bei n > 15 | Hart gegated | Optional Branch-and-Bound oder Christofides als Mittelweg |
| Multi-Truck-Flotte | Nicht implementiert | Aktuell genau 1 Fahrzeug — VRP-Erweiterung wäre nötig |
| Auth / Multi-User | Nicht implementiert | Out of Scope für Demo |
| Historisches KPI-Dashboard | Nicht implementiert | Route-Daten persistiert, aber nicht aggregiert |
| Eigenes OSRM-Hosting | Nutzt Public Demo | Bei Production-Deployment in eigene Infrastruktur |
| Predictive Fill-Level (ML) | Nicht implementiert | Zu wenig Daten; in größerem Pilot sinnvoll |
| Vollständige Wireframes | In Arbeit (Fulya) | Web-App + Touchpanel-Screens |
| Touchpanel-State-Diagramm | Ausstehend | Lieferung mit Wireframes |

---

## 12. Verweise

- **Projekt-Dokumentation:** `Dokumentation & Präsentation Neu/Dokumentation.typ` — vollständige Doku inkl. Hardware, Mechanik, Sprintplan, Persona
- **Briefing Wireframes:** `Briefing_Fulya_Wireframes.md` — Aufgabenstellung für UX-Arbeit
- **TSP-Benchmark:** `backend/scripts/tsp_benchmark.py` — empirischer NN-vs-2-opt-vs-Exact-Vergleich
- **Geocoder:** `backend/scripts/geocode_bins.py` — Nominatim-Batch zur Adress-Verortung
- **API-Vertrag** (für Pico-Firmware): `docs/api_contract.md`

---

*Diese Doku ist die kanonische Architektur-Referenz. Bei Code-Änderungen, die hier dokumentierte Entscheidungen verändern, bitte dieses File mit aktualisieren.*

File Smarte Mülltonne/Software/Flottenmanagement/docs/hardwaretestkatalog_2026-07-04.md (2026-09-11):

# Hardware-Testkatalog (Pico) — Stand 2026-07-04

Offene End-to-End-Tests am **physischen Pico**, die sich seit dem letzten
Hardware-Lauf angesammelt haben. Alle Features sind codeseitig fertig, committet
und `py_compile`-grün — sie brauchen nur noch die Verifikation an der echten Tonne.

## Setup vor den Tests

### A) Pico flashen (`DEV=/dev/cu.usbmodem14301`)

```bash
cd "Smarte Mülltonne/Software"; DEV=/dev/cu.usbmodem14301
mpremote connect port:$DEV fs cp Quellcode/Client/main.py :main.py
mpremote connect port:$DEV fs cp Quellcode/Client/global_controller_test.py :global_controller_test.py
mpremote connect port:$DEV fs cp Quellcode/Client/touchpanel.py :touchpanel.py
mpremote connect port:$DEV fs cp Quellcode/Client/config.py :config.py
# Touchpanel-UI + neues Confirm-Asset (laufende ui.py = firmware-Variante):
mpremote connect port:$DEV fs cp Flottenmanagement/firmware/pico_touchpanel/ui.py :ui.py
mpremote connect port:$DEV fs cp Flottenmanagement/firmware/pico_touchpanel/assets/confirm_report.rle :assets/confirm_report.rle
mpremote connect port:$DEV reset
```

Deckt ab: MUX-Pinout, Füllstand C8, Eco, Party, Meldungen, Deckel-Security.
> Zwei `ui.py` (firmware = läuft auf dem Pico, + `Client/ui.py` = Repo-Konsistenz) —
> auf den Pico kommt die **firmware**-Variante. **Nach dem `fs cp` nicht mehr `fs cat`
> aufrufen** (stoppt die laufende Firmware → sonst nochmal `reset`).

### B) Mac-Seite: Backend + Bridge neu starten (für T3 + T6 zwingend)

Beide **neu starten**, damit die neuen Endpoints/Poller aktiv sind
(Telemetry-`location_state`, `/arm-state`, Bridge-Arm-Poll, `UNAUTHORIZED_OPEN`):

```bash
# Backend (Port 8000)
cd "Smarte Mülltonne/Software/Flottenmanagement/backend" && .venv/bin/uvicorn main:app --host 0.0.0.0 --port 8000
# Bridge (Port 50002 -> Backend), in eigenem Terminal:
cd "Smarte Mülltonne/Software/Flottenmanagement/bridge" && python tcp_bridge.py --backend http://127.0.0.1:8000 --bin-id 22
```

### C) Verbindung prüfen

- Demo-Netz: Mac = `192.168.50.10`, WLAN `SmartBinDemo`, Bridge `:50002`, Backend `:8000`.
- Nach Pico-Reset im Bridge-Log erwartet: `Pico connected` → `pico: Pico ist bereit` → `STATUS:STANDBY`.
- Falls „alles leer" im Leitstand: Admin-Dashboard → Szenario **Schichtbeginn** setzen.

---

## T1 — MUX-Pinout (fundamental, zuerst testen!)

Neues Pinout: MUX **S0–S3 = GP1–GP4**, **SIG = GP5**, Füllstand auf **Kanal C8**.
US links/rechts unverändert (LEFT=7, RIGHT=6).

- [ ] **Sensoren lesen roh:** auf blankem Weiß alle 5 Linien-Sensoren = 0; Linie
      quer schieben → jeder Kanal schaltet einzeln nacheinander.
- [ ] **Linienverfolgung:** Fahrt auslösen → Position pendelt um 0, wenige
      `LINE_LOST`, kein Rausfahren (wie im 4200-Hz-Referenzlauf).
- [ ] **Hindernis:** Hand vor Frontsensor (<30 cm) → `OBSTACLE_WAIT`.
- [ ] ⚠️ Falls nichts sauber liest → physische MUX-Verdrahtung ≠ GP1–5 prüfen.

## T2 — Füllstand auf Kanal C8

Eigener US-Sensor (statt Front-Sensor), gemeinsamer Trigger GP6.

- [ ] Serieller `Fuellstand-Test`-Log zeigt plausible Abstände/Prozent von **C8**.
- [ ] Tonne füllen/leeren → Füllstand ändert sich; Touchpanel-Statusleiste aktualisiert.

## T3 — Touchpanel-Meldungen → Leitstand

Voraussetzung: Bridge + Backend laufen, Tonne 22 verbunden.

- [ ] Panel: Menü → PIN `12#` → „problem" → **HYGIENE** tippen.
- [ ] Panel zeigt Screen **„Meldung gesendet"** (gelbes Häkchen, gleicher Stil wie „Auswahl bestätigt").
- [ ] Meldung erscheint **live im Leitstand** (Security-Panel, Icon `Sparkles`, „Hygieneproblem gemeldet").
- [ ] Analog **SCHADEN** → Icon `Wrench`, „Beschädigung gemeldet".
- [ ] Operator „Erledigen" → Meldung verschwindet.
- [ ] Bridge-Log: `REPORT:HYGIENE`/`REPORT:DAMAGE` → `POST /security/events`.

## T4 — Eco-Modus (Display dimmen)

Backlight an **GP15** per PWM. Voraussetzung: Backlight physisch an GP15 (via Transistor).

- [ ] Panel: PIN `12#` → „energy" → **ECO** → Display dimmt sichtbar auf ~40 %.
- [ ] Nochmal **ECO** → wieder volle Helligkeit.
- [ ] ⚠️ Falls „voll" dunkler als vorher → GP15 braucht Transistor als Treiber (zu wenig GPIO-Strom).

## T5 — Party-Modus (Easter-Egg)

- [ ] Voraussetzung: Tonne im **Leerlauf** (`AT_HOME`), Platz zum Drehen frei.
- [ ] Panel: PIN-Screen → **`***`** → OK.
- [ ] Tonne dreht sich **zügig auf der Stelle** (~10 s) + Buzzer klopft den
      **„Shave and a haircut"**-Rhythmus.
- [ ] Nach ~10 s: Stop → zurück in den Leerlauf.

## T6 — Unbefugte Deckelöffnung → Alarm

Voraussetzung: **Bridge + Backend neu gestartet** (neuer Arm-State-Poll + Endpoint),
Füllstand-Sensor auf C8 funktioniert (T2). Zusätzlich flashen: nichts Neues nötig
(Pico-Logik steckt in `global_controller_test.py`, schon in der Deploy-Liste oben).

- [ ] **Zuhause = Einwurf:** Tonne im Leerlauf (`AT_HOME`), Deckel öffnen (Füllstand
      abdecken/kein Echo) → **kein** Alarm, keine Meldung.
- [ ] **Scharf an der Straße:** `goto_street` (Web-App **oder** Touchpanel) → Tonne
      wartet an der Abholpos. Web-App zeigt sie **unterwegs/an der Straße** (nicht mehr
      „zuhause" — Telemetry-Fix). Deckel öffnen → **sofort Buzzer-Alarm** + Meldung
      **„Unbefugtes Öffnen"** (Lock-Icon, rot) live im Security-Panel.
- [ ] **Alarm nicht umgehbar:** Deckel offen lassen → Buzzer läuft weiter; erst beim
      **Schließen** hört er auf.
- [ ] **Entschärfen per Truck:** Sim-Truck an die Position von Tonne 22 fahren (≤10 m,
      Admin/Route) → Bridge-Log `arm-state -> pico: DISARM`. Deckel öffnen → **kein**
      Alarm (Leerung). Truck weg → `ARM` → wieder scharf.
- [ ] Bridge-Log: `REPORT:UNAUTHORIZED_OPEN` → `POST /security/events` bei Alarm.
- [ ] „Erledigen" im Leitstand entfernt die Meldung.

---

## Reihenfolge-Empfehlung

**T1 zuerst** (MUX ist die Basis für alles Sensorische). Dann T2 (Füllstand),
T3 (Meldungen, braucht Bridge/Backend), T4 (Eco), T5 (Party — Spaß zum Schluss),
**T6 (Deckel-Security — braucht T2 + Bridge/Backend + optional Sim-Truck).**

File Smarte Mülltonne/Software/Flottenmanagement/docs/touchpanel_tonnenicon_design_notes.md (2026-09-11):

# Touchpanel Tonnen-Icons: Design- und Umsetzungsnotizen

Stand: 2026-06-22

Dieses Dokument beschreibt, wie die Tonnen-Icons im Touchpanel umgesetzt sind,
welche Designentscheidungen bisher gut funktioniert haben und wo die aktuellen
Probleme liegen. Es ist als Briefing fuer einen weiteren Coding-Agenten gedacht.

## Kontext

Die Touchpanel-Firmware liegt hier:

```text
Smarte Mülltonne/Software/Flottenmanagement/firmware/pico_touchpanel/
```

Die sichtbaren Screens werden nicht live aus SVGs gerendert, sondern als
vorgefertigte RLE-Bitmap-Assets geladen:

```text
firmware/pico_touchpanel/assets/*.rle
```

Der Renderer sitzt in:

```text
firmware/pico_touchpanel/wireframe.py
```

Die Screen-Logik sitzt in:

```text
firmware/pico_touchpanel/ui.py
```

Wichtig: Die beiden Hauptmenues mit den 4 Funktionsbuttons links/rechts werden
als komplette Screens geladen:

```text
assets/menu_1.rle
assets/menu_2.rle
```

Die Touchboxen liegen zwar in `ui.py`, aber die sichtbaren Button- und
Iconformen stecken in den RLE-Assets.

## Aktueller guter Stand / Rollback

Der letzte akzeptierte Stand vor dem fehlgeschlagenen Kontrastversuch wurde
gesichert unter:

```text
firmware/pico_touchpanel/backups/2026-06-22_before_menu_contrast_fix/
```

Darin liegen:

```text
assets/menu_1.rle
assets/menu_2.rle
ui.py
```

Dieser Stand ist aktuell wieder aktiv. Die Formen der Tonnen-Icons sind dort
grundsaetzlich richtig:

- Position der Tonnen innerhalb der Buttons passt.
- Skalierung der Icons passt.
- Button-Groessen und Button-Positionen passen.
- Pfeile, Statuspunkte und Zurueck-Pfeil passen.
- Gesamtkomposition des doppelseitigen Hauptmenues passt.

Bitte diesen Stand als geometrische Basis verwenden.

## Fehlgeschlagener Versuch

Ein Kontrastversuch wurde gesichert unter:

```text
firmware/pico_touchpanel/backups/2026-06-22_failed_menu_contrast_attempt/
```

Der Versuch hat die Tonnenkoerper in `menu_1.rle` und `menu_2.rle`
nachtraeglich per geometrischem Recoloring dunkler gemacht. Das war in der
Desktop-Vorschau besser, auf dem echten Display aber optisch ein Fail.

Bitte nicht auf diesem Versuch aufbauen.

Warum der Ansatz nicht funktioniert hat:

- Die Tonnen wurden zu plakativ und wirkten nicht mehr wie der vorherige
  Wireframe-Stil.
- Die feinen Proportionen und Layer der Icons wurden durch das grobe Uebermalen
  gestoert.
- Das Problem ist nicht nur "Tonne dunkler machen", sondern gezielter
  Material-/Layer-Kontrast innerhalb des bestehenden Designs.

## Aktuelles Problem

Auf dem echten Display wirken die Tonnen-Icons im Hauptmenue teilweise so, als
waeren sie nicht gefuellt.

Beobachtung:

- Der Tonnenkoerper hat fast dieselbe Farbe wie der Button-Hintergrund.
- Dadurch bleiben vor allem Deckel, Label, gelbe Symbole und schwarze Kanten
  sichtbar.
- Die eigentliche Tonnenflaeche verschmilzt mit dem Button.
- Bei Lichteinstrahlung wird das Problem deutlich staerker.

Kurz: Die Formen sind gut, aber der lokale Kontrast zwischen Button und
Tonnenkoerper ist zu schwach.

## Display-Learning

Das verwendete Touchdisplay zeigt feine Grauabstufungen schlecht:

- Grauverlaeufe wirken stufig.
- Grau auf Grau verliert bei Umgebungslicht schnell Kontrast.
- Dunkler Dark Mode wirkt auf dem Desktop gut, ist auf dem Panel aber schlechter
  lesbar.
- Gelb bleibt wichtig als Akzent, darf aber auf hellerem Grau nicht ausbleichen.

Deshalb:

- Keine subtilen Verlaeufe als Hauptkontrast verwenden.
- Nicht zu viele nah beieinanderliegende Grautoene nutzen.
- Wichtige Formen brauchen harte, aber stilistisch saubere Tonwerttrennung.
- Gelb moeglichst stabil lassen oder nur sehr vorsichtig anheben.

## Designentscheidungen fuer das Tonnen-Icon

Die Tonne soll weiterhin wie im Wireframe aussehen:

- schwarzer/dunkler Deckel mit gelbem Griff/Deckelakzent,
- kleines helles Rechteck/Touchpanel vorne oben,
- trapezfoermiger Tonnenkoerper,
- schwarze/dunkle Raeder und Standfuesse,
- dezente Vorderstruktur, aber nicht zu viel Detail,
- Funktionssymbol in Gelb vor/auf der Tonne,
- kein 8-Bit-/Pixelart-Stil,
- keine rein flache Silhouette ohne Wireframe-Anmutung.

Wichtige Erkenntnis aus den Statusscreen-Arbeiten:

- Formen muessen sauber bleiben.
- Nachtraegliches Uebermalen kompletter Koerperbereiche kann die Wirkung
  zerstoeren.
- Besser ist ein gezieltes Re-Exportieren oder Recoloring aus der Quelle mit
  klar definierten Layerfarben.

## Empfohlener Loesungsansatz

Nicht grob in den RLEs uebermalen. Besser:

1. Die aktuelle gute Version von `menu_1.rle` und `menu_2.rle` als Basis nehmen.
2. Falls moeglich aus der urspruenglichen SVG-/Designquelle neu exportieren.
3. Nur die Tonnenkoerper-Farbe in den Menue-Icons leicht vom Button absetzen.
4. Button-Hintergruende nicht stark veraendern, weil deren Position/Form bereits
   gut ist.
5. Deckel, gelbe Symbole, Pfeile und helle Label-Flaechen nicht veraendern.

Kontrastidee:

- Buttonflaeche: aktueller mittlerer Grauton darf bleiben oder minimal heller.
- Tonnenkoerper: etwas dunkler und neutraler als Button, aber nicht schwarz.
- Tonnen-Seiten/Kanten: minimal dunkler als Koerper.
- Label oben: hell lassen.
- Gelb: moeglichst unveraendert, weil es auf dem Panel gut sichtbar ist.

Wichtig: Tonnenkoerper soll sichtbar gefuellt sein, aber nicht wie ein grober
schwarzer Block wirken.

## Was nicht wiederholen

Bitte vermeiden:

- komplette Tonnenkoerper mit einem grossen Polygon hart zu uebermalen,
- den Tonnenkoerper zu dunkel zu machen,
- die Proportion der Tonne zu veraendern,
- Iconpositionen erneut zu verschieben,
- Buttonpositionen erneut zu verschieben,
- Gelb zu entsaettigen,
- Hintergrund/Button und Tonne mit denselben Grau-/Blauwerten zu belassen.

## Konkrete Dateien

Zu bearbeiten:

```text
firmware/pico_touchpanel/assets/menu_1.rle
firmware/pico_touchpanel/assets/menu_2.rle
```

Nur bei Bedarf:

```text
firmware/pico_touchpanel/ui.py
```

`ui.py` sollte fuer diese Aufgabe normalerweise nicht geaendert werden, weil die
Touchboxen und Screen-Navigation bereits passen.

## Testworkflow

Vor jedem Versuch:

1. Backup anlegen, z.B.

```text
firmware/pico_touchpanel/backups/YYYY-MM-DD_before_menu_recolor_attempt/
```

2. Mindestens sichern:

```text
assets/menu_1.rle
assets/menu_2.rle
ui.py
```

3. Assets aendern.
4. Nur `menu_1.rle` und `menu_2.rle` auf den Pico kopieren.
5. Pico resetten.
6. Direkt auf dem echten Display bei Raumlicht und Lichteinstrahlung bewerten.

Upload-Beispiel:

```bash
fw="/ABSOLUTER/PFAD/ZU/firmware/pico_touchpanel"
python3 -m mpremote connect /dev/cu.usbmodemXXXX cp "$fw/assets/menu_1.rle" :/assets/menu_1.rle
python3 -m mpremote connect /dev/cu.usbmodemXXXX cp "$fw/assets/menu_2.rle" :/assets/menu_2.rle
python3 -m mpremote connect /dev/cu.usbmodemXXXX reset
```

## Offene Designfrage

Neben den Tonnen-Icons gibt es ein allgemeines Lesbarkeitsproblem:

- Das UI ist sehr dunkel.
- Die Menues bestehen aus Grau auf Grau.
- Bei Lichteinstrahlung ist der Kontrast schwach.

Moeglicher spaeterer Schritt:

- den allgemeinen Menue-Hintergrund minimal heller oder neutraler machen,
- die Buttonflaechen klarer vom Hintergrund trennen,
- aber Gelb-Kontrast erhalten.

Dieser Schritt sollte getrennt vom Tonnen-Icon-Fix getestet werden. Erst die
Tonnen-Icons stabil bekommen, dann den allgemeinen Hintergrund anpassen.

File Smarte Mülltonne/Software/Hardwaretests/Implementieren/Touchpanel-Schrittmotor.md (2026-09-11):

# Uebergabe: Touchpanel mit PD-Schrittmotor-Regelung

Datum: 19.06.2026

## Ziel

Die bestehende Touchpanel-Firmware der smarten Muelltonne wurde mit der vorhandenen PD-Schrittmotor-Regelung fuer den Linienfolger verbunden. Die Fahrt zur Strasse soll ueber das Touchpanel gestartet werden.

Startpfad in der UI:

```text
PIN -> Fahren -> Abholung
```

Beim Druecken von `Abholung` startet die Muelltonne die Fahrt zur Strasse mit der PD-Regelung.

## Verwendete Ausgangsdateien

Aktuelle Touchpanel-Firmware:

```text
C:\Users\tpelz\OneDrive - fhsuedwf\2_Semester\Interdisziplinäres Projekt\Interdisziplin-res-Projekt-Smarte-M-lltonne-2.0\Smarte Mülltonne\Software\Flottenmanagement\firmware\pico_touchpanel
```

Wichtige vorhandene Dateien im Touchpanel-Projekt:

```text
main.py
config.py
display.py
touch.py
ui.py
wireframe.py
assets\
```

Vorhandener PD-Motorcode als fachliche Grundlage:

```text
C:\Users\tpelz\OneDrive - fhsuedwf\2_Semester\Interdisziplinäres Projekt\Interdisziplin-res-Projekt-Smarte-M-lltonne-2.0\Smarte Mülltonne\Software\Hardwaretests\pd_motor_linien.py
```

## Heute erzeugte und geaenderte Dateien

### 1. Neue integrierte `main.py`

Die aktuelle Touchpanel-`main.py` wurde durch eine integrierte Testversion ersetzt.

Zielpfad:

```text
C:\Users\tpelz\OneDrive - fhsuedwf\2_Semester\Interdisziplinäres Projekt\Interdisziplin-res-Projekt-Smarte-M-lltonne-2.0\Smarte Mülltonne\Software\Flottenmanagement\firmware\pico_touchpanel\main.py
```

Inhaltlich neu in dieser Datei:

- Import von `PWM` und Zeitfunktionen fuer die Motorsteuerung.
- Vollstaendige PD-Regler-Logik direkt in `main.py`.
- Multiplexer-Auswahl fuer CD74HC4067.
- Liniensensor-Auswertung ueber C0-C4.
- Ultraschallmessung vorne ueber Trigger GP6 und Echo auf Multiplexer-Kanal C5.
- Schrittmotorsteuerung ueber STEP/DIR/ENABLE.
- Start der Fahrt bei Touchpanel-Aktion `goto_street`.
- Anzeige von Zwischen- und Ergebnisbildschirmen:
  - `FAEHRT / PD REGLER AKTIV`
  - `ZIEL / STRASSE ERREICHT`
  - `STOPP / HINDERNIS`
  - `STOPP / LINIE VERLOREN`

### 2. Backup der alten `main.py`

Vor dem Ersetzen wurde die bisherige Datei gesichert:

```text
C:\Users\tpelz\OneDrive - fhsuedwf\2_Semester\Interdisziplinäres Projekt\Interdisziplin-res-Projekt-Smarte-M-lltonne-2.0\Smarte Mülltonne\Software\Flottenmanagement\firmware\pico_touchpanel\main_backup_before_pd_integration.py
```

Diese Datei enthaelt die vorherige reine Touchpanel-Startlogik ohne Motorintegration.

### 3. Zwischenversionen im Arbeitsordner

Im lokalen Arbeitsordner wurden zusaetzlich Test-/Zwischendateien erstellt:

```text
C:\Users\tpelz\OneDrive\Dokumente\Interdisziplinäres Projekt\main_integrated_touch_pd.py
C:\Users\tpelz\OneDrive\Dokumente\Interdisziplinäres Projekt\pd_motor_linien_touch.py
```

Wichtig: Fuer den Pico-Test ist aktuell nur die integrierte `main.py` entscheidend. Die separate Datei `pd_motor_linien_touch.py` wird von der aktuellen Pico-`main.py` nicht mehr importiert.

## Warum die Integration direkt in `main.py` gemacht wurde

Zuerst wurde eine modulare Loesung mit separatem Motor-Modul erstellt:

```python
from pd_motor_linien_touch import create_motors, run_to_street
```

Dabei trat beim Ausfuehren auf dem Pico das Problem auf, dass `pd_motor_linien_touch.py` nicht bekannt war. Ursache: Beim Ausfuehren ueber MicroPico oder "Run current file" wird haeufig nur die aktuell geoeffnete Datei uebertragen, nicht automatisch alle lokalen Zusatzmodule.

Gemeinsame Erkenntnis:

Fuer einen schnellen Hardwaretest ist eine Ein-Datei-Integration robuster, weil dann die Motorlogik direkt in `main.py` liegt und kein zusaetzliches Python-Modul auf dem Pico vorhanden sein muss.

## Aktueller Stand auf dem Pico

Die neue integrierte `main.py` wurde mit `mpremote` auf den Pico kopiert.

Pruefung auf dem Pico ergab:

```text
main.py 14847 Bytes
```

Danach wurde ein Reset ausgefuehrt:

```powershell
python -m mpremote reset
```

Damit startet der Pico beim Booten direkt mit der neuen Touchpanel-PD-Testversion.

## Testablauf

1. Pico einschalten oder resetten.
2. Touchpanel startet.
3. In der UI den Wartungs-/PIN-Bereich oeffnen.
4. PIN eingeben.
5. Menuepunkt `Fahren` auswaehlen.
6. `Abholung` druecken.
7. Display zeigt `FAEHRT / PD REGLER AKTIV`.
8. Die PD-Regelung uebernimmt die Schrittmotorsteuerung.

Die Fahrt wird beendet bei:

- Zielmarkierung `street`: Alle fuenf Liniensensoren erkennen den Linienwert.
- Hindernis vorne: Ultraschallabstand kleiner/gleich `US_STOP_CM`.
- Linie verloren: Keine Linie fuer laenger als `LOST_LINE_STOP_MS`.

## Aktuelle Hardware-Pinbelegung aus dem integrierten Code

### Multiplexer CD74HC4067

```text
S0  -> GP2
S1  -> GP3
S2  -> GP4
S3  -> GP5
SIG -> GP28
```

### Ultraschall vorne

```text
Trigger -> GP6
Echo    -> Multiplexer C5
```

### Liniensensoren

```text
C0-C4 am Multiplexer
Reihenfolge im Code: [0, 1, 2, 3, 4]
Gewichte: [2, 1, 0, -1, -2]
```

### Schrittmotor links

```text
DIR    -> GP10
STEP   -> GP11
ENABLE -> GP12
```

### Schrittmotor rechts

```text
DIR    -> GP13
STEP   -> GP8
ENABLE -> GP9
```

## Aktuelle Regelparameter

```text
BASE_SPEED = 45
MIN_FREQ = 2000
MAX_FREQ = 4500
KP = 32
KD = 2
MAX_CORRECTION = 60
MAX_DERIVATIVE_PER_S = 45
CONTROL_INTERVAL_MS = 25
LOST_LINE_STOP_MS = 10000
US_STOP_CM = 15
```

## Wichtige Erkenntnisse

### 1. Der aktuelle Touchpanel-Code ist modular

Die aktuelle Firmware besteht nicht aus einer einzelnen Touchpanel-Datei, sondern aus mehreren Modulen:

```text
main.py
config.py
display.py
touch.py
ui.py
wireframe.py
assets\
```

Die UI-Aktion fuer die Fahrt zur Strasse existiert bereits:

```python
goto_street
```

Sie wird in der UI ueber das Untermenue `fahren` durch `Abholung` ausgeloest.

### 2. `goto_street` ist der richtige Anknuepfpunkt

In `ui.py` ist fuer das Fahrmenue definiert:

```python
if key == "fahren":
    return (("HEIM", "goto_home"), ("ABHOLUNG", "goto_street"))
```

Deshalb wurde die Motorfahrt nicht auf einen beliebigen Screen gelegt, sondern gezielt an `goto_street` angebunden.

### 3. Separate Module muessen auf dem Pico vorhanden sein

Wenn eine Datei auf dem Pico Folgendes importiert:

```python
from pd_motor_linien_touch import run_to_street
```

muss `pd_motor_linien_touch.py` ebenfalls auf dem Pico liegen. Sonst bricht der Start mit einem Importfehler ab.

Fuer den aktuellen Test wurde deshalb alles direkt in `main.py` integriert.

### 4. `mpremote` konnte den Pico spaeter erreichen

Ein frueherer Versuch meldete:

```text
mpremote: no device found
```

Spaeter war der Pico erreichbar, und die neue `main.py` konnte erfolgreich hochgeladen werden.

### 5. Syntax wurde geprueft

Die integrierte Datei wurde vor dem Hochladen mit Python kompiliert:

```powershell
python -m py_compile main_integrated_touch_pd.py
```

Die Ziel-`main.py` wurde ebenfalls syntaktisch geprueft. Wegen Schreibrechten im OneDrive-Zielordner wurde dafuer ein separater Cachepfad verwendet.

## Hinweise fuer den naechsten Test

- Falls die Muelltonne rueckwaerts faehrt, muessen diese Werte getauscht werden:

```python
LEFT_FORWARD_DIR = 1
RIGHT_FORWARD_DIR = 0
```

- Falls die Liniensensoren auf schwarzer Linie `0` statt `1` liefern, muss dieser Wert angepasst werden:

```python
LINE_DETECTED_VALUE = 1
```

- Falls die Zielmarkierung zu frueh oder gar nicht erkannt wird, liegt es wahrscheinlich an dieser Logik:

```python
if all(value == LINE_DETECTED_VALUE for value in values):
    return "street"
```

- Falls die Muelltonne zu stark pendelt:

```python
KP reduzieren
KD leicht erhoehen oder reduzieren
BASE_SPEED verringern
```

- Falls sie zu langsam oder unzuverlaessig startet:

```python
BASE_SPEED erhoehen
MIN_FREQ/MAX_FREQ pruefen
ENABLE_ACTIVE_VALUE pruefen
```

## Rueckweg zum alten Zustand

Wenn die alte reine Touchpanel-Version wiederhergestellt werden soll:

```powershell
python -m mpremote cp "C:\Users\tpelz\OneDrive - fhsuedwf\2_Semester\Interdisziplinäres Projekt\Interdisziplin-res-Projekt-Smarte-M-lltonne-2.0\Smarte Mülltonne\Software\Flottenmanagement\firmware\pico_touchpanel\main_backup_before_pd_integration.py" :main.py
python -m mpremote reset
```

## Aktueller Uebergabestatus

- Touchpanel-Firmware nutzt weiterhin die vorhandenen Module fuer Display, Touch, UI und Assets.
- Die Fahrt zur Strasse ist in der aktuellen `main.py` direkt integriert.
- Start der Fahrt erfolgt ueber `PIN -> Fahren -> Abholung`.
- Datei wurde auf den Pico kopiert und per Reset gestartet.
- Der naechste Schritt ist der reale Hardwaretest mit angeschlossenen Motoren, Liniensensoren, Multiplexer und Ultraschallsensor.

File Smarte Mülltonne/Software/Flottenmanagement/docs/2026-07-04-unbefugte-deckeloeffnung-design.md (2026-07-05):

# Design-Spec: Unbefugte Deckelöffnung → Alarm (Buzzer + Leitstand)

Stand: 2026-07-04 · Status: abgenommen (Brainstorming), bereit für Umsetzungsplan

## 1. Ziel

Die Tonne erkennt eine **Deckelöffnung** und entscheidet, ob sie **legitim**
(Einwurf zuhause / Leerung durch den Müllwagen) oder **unbefugt** ist. Bei einer
unbefugten Öffnung reagiert sie **sofort beim Öffnen**:

- **Buzzer-Alarm** am Fahrzeug (Abschreckung),
- **`unauthorized_open`-Meldung live im Leitstand** (Security-Panel).

Sofort-beim-Öffnen (nicht beim Schließen) ist bewusst: Abschreckeffekt + nicht
umgehbar durch „Deckel offen lassen und abhauen".

## 2. Ist-Zustand (verifiziert)

- **Deckel-offen-Erkennung existiert heuristisch:** `FuellstandSensor.is_deckel_offen()`
  wird True, wenn der Füllstand-Ultraschall (Kanal C8) mehrfach **kein Echo** liefert
  (`no_echo_for_deckel_offen=3`). Aktuell nur ~alle 2 s gemessen → ~6 s träge.
- **Geofence existiert schon** in `services/truck_simulator.py`:
  `ARRIVAL_THRESHOLD_M = 10.0`; bei Annäherung des Trucks wird die Tonne
  losgeschickt (`_schedule_bin_move(pickup)`), bei `_haversine_m(pos, bin) <= 10 m`
  erfolgt `_empty_bin`. Backend kennt Truck-Position (`truck_state`) + Bin-Position.
- **Sim bewegt nur virtuelle Tonnen** (1–35). Die **physische Tonne 22** wird
  **manuell** über die Web-App (`goto_street`) losgeschickt — „Nutzer schickt Tonne
  eher zur Straße" ist bei 22 also der Normalfall.
- **SecurityEvent** unterstützt `event_type` als freien String; `unauthorized_open`
  war von Anfang an ein vorgesehener Typ. WS broadcastet offene Events; Security-Panel
  zeigt sie + „Erledigen". *(Zu prüfen: Label/Icon für `unauthorized_open` im Frontend.)*
- **Bridge** relayt Pico-Zeilen (`STATUS`/`ARRIVED`/`ACK`) ↔ Backend und pollt
  `/bins/22/pending-command`. `_bridge_send`/`REPORT:`-Mechanik ist da (Meldungs-Slice).
- **Lücke:** Eine **Touchpanel-`goto_street`** setzt im Backend nur `status="en_route"`,
  aber **nicht** `location_state`/Position (erst bei `ARRIVED:STREET`). Web-App zeigt die
  Tonne während der Fahrt noch „zuhause".

## 3. Klassifizierungs-Regel

**Scharf (armed) = Deckel-Öffnung löst Alarm aus**, außer in zwei Fällen:

| Deckel öffnet, wenn … | Bewertung |
|---|---|
| **zuhause** (`AT_HOME`/`PARTY`) | Einwurf → erlaubt (der Pico weiß das lokal) |
| **Truck aktiv am Leeren** (Truck ≤ 10 m, Backend meldet „disarm") | Leerung → erlaubt |
| **sonst** (Fahren, an der Abholpos ohne Truck, geparkt) | **unbefugt → Alarm** |

Bewusst: **entschärft nur bei tatsächlicher Leerung** (Truck wirklich da), nicht
schon beim Losfahren — so bleibt die manuell rausgeschickte Tonne die ganze Wartezeit
an der Straße geschützt.

## 4. Architektur & Datenfluss

```
Pico (lokal):
  Deckel-Monitor (schnell, ~500 ms): FuellstandSensor -> deckel_offen
  armed = (state NICHT in {AT_HOME, PARTY}) UND (nicht disarm_by_truck)
  deckel geht auf & armed  ->  SOFORT:
        buzzer.play(alarm_pattern, repeat)        (Abschreckung)
        _bridge_send("REPORT:UNAUTHORIZED_OPEN")   (einmal pro Öffnung)
  deckel zu / wieder disarmed  ->  buzzer aus

Backend (Geofence, erbt truck_simulator):
  disarm(bin) = _haversine_m(truck_pos, bin_pos) <= ARRIVAL_THRESHOLD_M (10 m)
  -> als Arm/Disarm-Zustand bereitstellen (Endpoint, den die Bridge pollt)

Bridge:
  pollt Arm/Disarm-Zustand -> sendet "ARM"/"DISARM" an den Pico bei Wechsel
  relayt "REPORT:UNAUTHORIZED_OPEN" -> POST /security/events
        {bin_id: 22, event_type: "unauthorized_open"}

Backend -> WS -> Security-Panel (live), "Erledigen" wie bei den Meldungen.
```

## 5. Komponenten & Änderungen

1. **Pico `global_controller_test.py`**
   - Deckel-Monitor als Querschnitts-Check in `run()` (throttled ~500 ms): misst
     Füllstand → `deckel_offen`. Schnellere Bestätigung (z. B. `no_echo=2`) für knackige
     Reaktion; Kompromiss gegen Fehlalarm.
   - `self._armed_by_truck_disarm` (Flag, gesetzt von `handle_network_command("ARM"/"DISARM")`).
   - `armed`-Ableitung + Alarm-Logik (Buzzer-Pattern + einmalig `REPORT:UNAUTHORIZED_OPEN`
     pro Öffnungs-Transition; Buzzer läuft bis Deckel zu / disarmed).
   - `handle_network_command`: neue Kommandos `ARM`/`DISARM`.
2. **Bridge `tcp_bridge.py`**
   - Arm/Disarm-Zustand vom Backend pollen → `ARM`/`DISARM` an Pico bei Änderung.
   - `REPORT:UNAUTHORIZED_OPEN` → `POST /security/events {event_type:"unauthorized_open"}`.
3. **Backend**
   - Geofence-Auswertung für Bin 22 (Distanz Truck↔Bin ≤ 10 m) → Arm/Disarm-Zustand
     bereitstellen (kleiner Endpoint oder Feld, das die Bridge pollt). Reuse
     `_haversine_m` + `truck_state`.
   - **Telemetry-Fix** (`routers/bins.py`): pico_state → `location_state` mappen
     (`MANUAL_GOTO_STREET_REQUEST`→`moving_to_pickup`, `MANUAL_RETURN_HOME_REQUEST`→
     `moving_home`, `WAIT_AT_STREET`→`truck`, `STANDBY`/`AT_HOME`→`home`), damit eine
     Touchpanel-Fahrt Web-App + Backend-Zustand sofort konsistent überschreibt.
   - `SecurityEvent(unauthorized_open)` bleibt (freier event_type).
4. **Frontend**
   - Prüfen/ergänzen: Label + Icon für `event_type="unauthorized_open"` in
     `lib/labels.ts` + `SecurityPanel.tsx` (falls noch nicht vorhanden). Erledigen-Loop existiert.

## 6. Fehlerbehandlung & Grenzen (YAGNI)

- Deckel-Erkennung ist heuristisch (kein Echo). Fehlmessungen → durch N-Bestätigung
  gedämpft; Kompromiss Reaktionszeit ↔ Fehlalarm ist ein Tuning-Knopf.
- `_bridge_send` fehlertolerant: offline geht die Meldung best-effort verloren; der
  **Buzzer-Alarm läuft lokal trotzdem** (Abschreckung unabhängig vom Netz).
- Fällt der Arm/Disarm-Poll aus (Bridge/Backend weg), bleibt der zuletzt bekannte
  Zustand; Default = **scharf, sobald außer Haus** (sicherheitskonservativ).
- Deckel-Check läuft auch während der Fahrt (~8 ms Messung / 500 ms = akzeptabler Jitter).
- Ein Alarm/Event pro Öffnung (kein Spam), reset bei Deckel-zu.

## 7. Verifikation

- **Backend/Bridge isoliert:** Truck-Position nah/fern an Bin 22 setzen →
  Arm/Disarm-Zustand kippt; simulierte `REPORT:UNAUTHORIZED_OPEN` → `GET /security/events`.
- **Telemetry:** Touchpanel-`goto_street` → Bin 22 `location_state=moving_to_pickup`
  → Web-App zeigt „unterwegs" (nicht mehr „zuhause").
- **End-to-End (Demo):** `goto_street` (Web-App oder Touchpanel) → Tonne wartet an der
  Straße = **scharf** → Deckel öffnen → **Buzzer + `unauthorized_open` im Leitstand**.
  Sim-Truck erreicht Bin 22 (≤10 m) = **entschärft** → Deckel öffnen → kein Alarm.
  Zuhause: Deckel öffnen → kein Alarm.

## 8. Nicht im Scope

- Kein echter Deckel-Sensor (bleibt Füllstand-Heuristik).
- Kein physischer Schließmechanismus / Verriegelung.
- Kein Retry/Queue der Meldung bei Offline (Buzzer reicht lokal).
- Kein Auto-Dispatch der **physischen** Tonne 22 durch den Sim (bleibt manuell).

## 9. Getroffene Entscheidungen

- Erkennung **beim Öffnen** (sofort), nicht beim Schließen.
- Klassifizierung: **scharf = außer zuhause**; **entschärft = zuhause ODER Truck aktiv
  am Leeren (≤10 m)**.
- Geofence: **vorhandenen `truck_simulator`/`ARRIVAL_THRESHOLD_M=10 m` wiederverwenden**.
- Alarm = **Buzzer (lokal, sofort) + `unauthorized_open`-SecurityEvent** (reuse Meldungs-Infra).
- **Telemetry-Fix** für Touchpanel-Dispatch gehört mit in den Slice.

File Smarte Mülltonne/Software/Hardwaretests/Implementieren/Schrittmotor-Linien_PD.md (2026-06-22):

# Uebergabe Linienfolger mit PD-Regler und Schrittmotoren

Stand: 19.06.2026

Diese Datei dokumentiert die heute erstellten und geaenderten Codezeilen fuer den Pico-Linienfolger der smarten Muelltonne. Der aktuelle Code liegt in:

`linienfolger_pd_stepper.py`

## Ziel

Die Muelltonne soll mit zwei Schrittmotoren einer Linie folgen. Die Liniensensoren werden ueber einen CD74HC4067 Multiplexer eingelesen. Die Motoren werden ueber STEP/DIR/ENABLE-Treiber angesteuert. Die Korrektur der Fahrtrichtung erfolgt ueber einen PD-Regler.

Zusatzfunktionen:

- Wenn die Linie kurz verloren geht, wird die letzte berechnete Motoransteuerung beibehalten.
- Wenn die Linie laenger verloren bleibt, stoppen die Motoren nach 5 Sekunden.
- Wenn alle fuenf Liniensensoren gleichzeitig Linie erkennen, stoppt die Muelltonne, weil sie an der Strasse angekommen ist.
- Der vordere Ultraschallsensor stoppt die Muelltonne bei einem Hindernis vor der Tonne.

## Pinbelegung

### Multiplexer CD74HC4067

```python
MUX_S0_PIN = 2
MUX_S1_PIN = 3
MUX_S2_PIN = 4
MUX_S3_PIN = 5
MUX_SIGNAL_PIN = 28
```

### Liniensensoren

Die Liniensensoren liegen auf den Multiplexer-Kanaelen `C0` bis `C4`.

```python
LINE_CHANNELS = [0, 1, 2, 3, 4]
```

Wichtiges Ergebnis aus den Tests: Die Sensoren sind mechanisch bzw. logisch von rechts nach links angeordnet. Deshalb ist die Gewichtung aktuell:

```python
LINE_WEIGHTS = [2, 1, 0, -1, -2]
```

Die Sensoren liefern bei erkannter Linie aktuell `1`.

```python
LINE_DETECTED_VALUE = 1
```

Falls die Sensoren spaeter invertiert betrieben werden, muss dieser Wert auf `0` geaendert werden.

### Ultraschallsensor vorne

Der vordere Ultraschallsensor wurde heute in den Code integriert.

```python
US_TRIGGER_PIN = 6
US_FRONT_CHANNEL = 5
US_STOP_CM = 30
US_INTERVAL_MS = 120
US_TIMEOUT_US = 30000
```

Der Trigger ist direkt an `GP6` angeschlossen. Das Echo-Signal kommt ueber den Multiplexer-Kanal `C5` und wird deshalb ueber `MUX_SIGNAL_PIN = 28` eingelesen.

Wenn die gemessene Entfernung kleiner oder gleich `30 cm` ist, stoppen die Motoren sofort.

### Motoren

Die Motorpins wurden an die getestete Motoransteuerung angepasst:

```python
LEFT_DIR_PIN = 10
LEFT_STEP_PIN = 11
LEFT_ENABLE_PIN = 12

RIGHT_DIR_PIN = 13
RIGHT_STEP_PIN = 8
RIGHT_ENABLE_PIN = 9
```

Die getestete Vorwaertsfahrt ist:

```python
LEFT_FORWARD_DIR = 0
RIGHT_FORWARD_DIR = 1
```

## Motoransteuerung

Die Schrittmotoren werden nicht mit festen Schrittbloecken gefahren, sondern ueber PWM auf den STEP-Pins. Die Frequenz der PWM bestimmt die Motorgeschwindigkeit.

Die Klasse dafuer ist:

```python
class DualStepperMotorPWM:
```

Die wichtigste Methode ist:

```python
drive_forward_differential(left_speed, right_speed)
```

Diese Methode setzt getrennte Geschwindigkeiten fuer linken und rechten Motor. Dadurch kann der PD-Regler lenken.

Die Umrechnung von Prozent-Geschwindigkeit in Frequenz passiert hier:

```python
def _speed_to_frequency(self, speed, trim_factor):
```

Aktuelle Frequenzgrenzen:

```python
MIN_FREQ = 2000
MAX_FREQ = 4500
```

Formel:

```text
Frequenz = MIN_FREQ + (MAX_FREQ - MIN_FREQ) * speed / 100
```

Bei `speed = 0` wird keine PWM ausgegeben.

## PD-Regler

Der PD-Regler berechnet aus der Linienposition eine Korrektur.

Aktuelle Parameter:

```python
KP = 32
KD = 2
MAX_CORRECTION = 60
MAX_DERIVATIVE_PER_S = 45
```

Aktuelle Fahrparameter:

```python
BASE_SPEED = 45
MIN_SPEED = 0
MAX_SPEED = 95
```

Die Korrektur wird symmetrisch auf die Motoren verteilt:

```python
left_speed = BASE_SPEED - correction
right_speed = BASE_SPEED + correction
```

Das bedeutet:

- Positive Korrektur: linker Motor langsamer, rechter Motor schneller.
- Negative Korrektur: linker Motor schneller, rechter Motor langsamer.

Diese symmetrische Variante wurde zum Schluss wiederhergestellt, weil die asymmetrische Variante mit nur einem verlangsamten Motor nicht ausreichend gut funktionierte.

## Wichtige Erkenntnisse aus den Tests

### 1. Sensorreihenfolge war gespiegelt

In den Ausgaben wurde sichtbar, dass z.B. Sensor `C3` zuerst als falsche Seite interpretiert wurde. Die Gewichtung musste deshalb auf:

```python
LINE_WEIGHTS = [2, 1, 0, -1, -2]
```

geaendert werden.

### 2. Vorwaertsfahrt der Motoren

Die richtige Vorwaertsfahrt ist:

```python
LEFT_FORWARD_DIR = 0
RIGHT_FORWARD_DIR = 1
```

An diesen Werten sollte nicht weiter gedreht werden, solange der normale Geradeauslauf funktioniert.

### 3. Linksdrehung war zu schwach

In den Logs war zu sehen, dass der Regler zwar am Limit war, aber der langsame Motor trotzdem noch mit ca. `2125 Hz` lief. Ursache war `MIN_SPEED = 5`, was wegen `MIN_FREQ = 2000` immer noch eine relativ hohe Frequenz erzeugte.

Deshalb wurde gesetzt:

```python
MIN_SPEED = 0
MAX_CORRECTION = 60
KP = 32
KD = 2
```

Dadurch kann ein Motor bei starker Korrektur wirklich stehen bleiben.

### 4. D-Anteil war zeitweise zu aggressiv

In einem Log sprang die Korrektur kurz in die Gegenrichtung. Vermutlich kam das vom D-Anteil. Deshalb wurde `KD` reduziert:

```python
KD = 2
```

Wenn der Roboter spaeter stark schwingt, zuerst `KD` leicht erhoehen oder `KP` leicht senken. Wenn er zu traege reagiert, zuerst `KP` leicht erhoehen.

### 5. Verhalten bei verlorener Linie

Die erste Suchlogik mit fester `SEARCH_SPEED` wurde entfernt. Stattdessen behaelt der Code jetzt die zuletzt berechnete Geschwindigkeit bei:

```python
last_left_speed = left_speed
last_right_speed = right_speed
```

Wenn keine Linie erkannt wird:

```python
left_speed = last_left_speed
right_speed = last_right_speed
motors.drive_forward_differential(left_speed, right_speed)
```

Nach 5 Sekunden ohne Linie wird gestoppt:

```python
LOST_LINE_STOP_MS = 5000
```

### 6. Strassenerkennung

Wenn alle fuenf Liniensensoren gleichzeitig Linie erkennen, wird `"street"` zurueckgegeben:

```python
if all(value == LINE_DETECTED_VALUE for value in values):
    return "street"
```

Im Hauptprogramm stoppt die Muelltonne dann sofort.

### 7. Ultraschall hat Vorrang

Der vordere Ultraschallsensor wird alle `120 ms` gemessen:

```python
US_INTERVAL_MS = 120
```

Der Stopp bei Hindernis wird vor Linienfolge und Strassenerkennung geprueft:

```python
if obstacle_detected(front_distance_cm):
    motors.stop()
```

Damit hat ein Hindernis vor der Muelltonne Vorrang vor allen Linienentscheidungen.

## Debug-Ausgabe

Die Ausgabe enthaelt aktuell:

```text
Sensoren
Position
Korrektur
Speed L/R
Frequenz L/R
US vorne
```

Beispiel:

```text
Sensoren: [0, 0, 1, 0, 0] Position: 0.0 Korrektur: 0.0 Speed L/R: 45.0 45.0 Frequenz L/R: 3125 3125 US vorne: None
```

Diese Ausgabe ist fuer die weitere Abstimmung wichtig.

## Naechste sinnvolle Tests

1. Geradeausfahrt testen:
   - Erwartung bei mittlerem Sensor: `Position: 0.0`, beide Geschwindigkeiten gleich.

2. Linke und rechte Abweichung einzeln testen:
   - Linie unter rechtem/linkem Sensor halten.
   - Pruefen, ob sich die Geschwindigkeiten sinnvoll gegensaetzlich aendern.

3. Starke Kurve testen:
   - Bei `Position: 2.0` oder `Position: -2.0` sollte ein Motor sehr langsam oder aus sein.

4. Linienverlust testen:
   - Wenn alle Sensoren `0` melden, muss die letzte Geschwindigkeit fuer maximal 5 Sekunden beibehalten werden.
   - Danach muss `Speed L/R: 0 0` erscheinen.

5. Strassenerkennung testen:
   - Wenn alle Sensoren `1` melden, muss sofort gestoppt werden.

6. Ultraschall vorne testen:
   - Hindernis unter `30 cm` vor den Sensor halten.
   - Erwartung: Motoren stoppen sofort.

## Parameter fuer weitere Abstimmung

Wenn die Muelltonne zu langsam reagiert:

```python
KP = 36
```

Wenn sie schwingt:

```python
KP = 28
```

oder:

```python
KD = 3
```

Wenn sie insgesamt zu schnell ist:

```python
BASE_SPEED = 35
```

Wenn die Motoren bei niedriger Geschwindigkeit nicht sauber drehen, aber nicht komplett stoppen sollen:

```python
MIN_SPEED = 5
```

Wenn die maximale Korrektur zu aggressiv ist:

```python
MAX_CORRECTION = 45
```

## Aktueller wichtiger Codezustand

Die wichtigste Kombination am Ende des Tages ist:

```python
LINE_WEIGHTS = [2, 1, 0, -1, -2]
LEFT_FORWARD_DIR = 0
RIGHT_FORWARD_DIR = 1

BASE_SPEED = 45
MIN_SPEED = 0
MAX_SPEED = 95

KP = 32
KD = 2
MAX_CORRECTION = 60

LOST_LINE_STOP_MS = 5000

US_TRIGGER_PIN = 6
US_FRONT_CHANNEL = 5
US_STOP_CM = 30
```

Diese Werte sind der aktuelle Ausgangspunkt fuer die naechsten Fahrtests.

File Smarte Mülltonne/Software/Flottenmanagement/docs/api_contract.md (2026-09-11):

# Hardwarevertrag: Legacy-Pico ↔ TCP-Bridge ↔ Backend

> Stand: Mai 2026. Dieser Vertrag beschreibt den ersten Vertical Slice mit der
> bestehenden MicroPython-Firmware aus `Software/Quellcode/Client`.

## Zielbild

Die alte Pico-Firmware bleibt der autonome Echtzeit-Kern: Linienverfolgung,
Motorsteuerung, Hindernisverhalten, Füllstandsmessung, Buttons, LEDs und Buzzer
laufen lokal auf dem Pico. Die Web-App übernimmt Flottenmanagement,
Visualisierung und Missionsbefehle.

Eine kleine Bridge verbindet beide Welten:

```text
Pico MicroPython
  TCP Zeilenprotokoll
  ↕
TCP Bridge auf Laptop (:50002)
  HTTP/JSON
  ↕
FastAPI Backend (:8000)
  ↕
Dashboard / Agent
```

Damit bleibt das Team für den Prof flexibel:

- Kurzfristig: alter Pico-Code bleibt nutzbar, TCP-Demo funktioniert weiter.
- Langfristig: Bridge kann durch direkte HTTP-Polling-Firmware ersetzt werden,
  ohne Dashboard und Backend umzubauen.

---

## Lokalbetrieb

Auf dem Server-Laptop:

```bash
# Terminal 1
cd Software/Flottenmanagement/backend
.venv/bin/uvicorn main:app --port 8000

# Terminal 2
cd Software/Flottenmanagement
python bridge/tcp_bridge.py --bin-id 1 --backend http://localhost:8000

# Terminal 3
cd Software/Flottenmanagement/frontend
npm run dev
```

Im alten Pico-Code:

```python
SERVER_IP = "<IP des Server-Laptops>"
SERVER_PORT = 50002
```

Ein Laptop reicht. Ein zweiter Laptop kann optional nur das Dashboard im Browser
öffnen.

---

## Pico ↔ Bridge: TCP-Zeilenprotokoll

Transport:

- TCP-Server: Bridge auf Port `50002`
- Client: Pico verbindet sich zum Laptop
- Framing: eine UTF-8-Zeile pro Nachricht, beendet mit `\n`

### Handshake

Pico sendet nach Connect:

```text
Pico ist bereit
```

Bridge interpretiert das als `STANDBY`-Telemetrie für das Backend.

### Statusmeldungen

Pico sendet regelmäßig:

```text
STATUS:STANDBY
STATUS:FULL
STATUS:LINE_FOLLOWING
STATUS:LINE_LOST
STATUS:OBSTACLE
STATUS:USER_PAUSED
STATUS:WAIT_AT_STREET
STATUS:EMPTIED
```

Bridge übersetzt diese Zustände in `POST /bins/{bin_id}/telemetry`.

### Ankunft

Pico sendet:

```text
ARRIVED: STREET
ARRIVED: HOME
```

Bridge setzt daraus:

| Pico | Backend-Telemetrie |
|---|---|
| `ARRIVED: STREET` | `pico_state = WAIT_AT_STREET` |
| `ARRIVED: HOME` | `pico_state = STANDBY` |

### Commands

Bridge sendet an den Pico:

```text
CMD_GOTO_STREET
CMD_RETURN_HOME
CMD_STOP
```

Pico bestätigt:

```text
ACK CMD_GOTO_STREET
ACK CMD_RETURN_HOME
ACK CMD_STOP
```

Bridge bestätigt danach zurück an den Pico:

```text
ACK_RECEIVED CMD_GOTO_STREET
ACK_RECEIVED CMD_RETURN_HOME
ACK_RECEIVED CMD_STOP
```

Das erhält die bestehende Hard-Offline-Startsequenz der alten Firmware.

---

## Bridge ↔ Backend: HTTP/JSON

### 1. Bridge pollt Backend-Commands

```http
GET /bins/{bin_id}/pending-command
```

Antwort, wenn kein Command wartet:

```json
null
```

Antwort mit Command:

```json
{
  "id": 42,
  "bin_id": 1,
  "action": "goto_street",
  "params": null,
  "created_at": "2026-05-20T12:00:00+00:00"
}
```

### 2. Command-Mapping

| Backend `action` | Bridge → Pico |
|---|---|
| `goto_street` / `go_to_street` / `start` | `CMD_GOTO_STREET` |
| `return_home` / `go_home` | `CMD_RETURN_HOME` |
| `stop` / `pause` / `lock` | `CMD_STOP` |

Nicht unterstützte Commands werden von der Bridge als fehlgeschlagen bestätigt,
damit die Queue nicht blockiert.

### 3. Bridge bestätigt Backend-Command

```http
POST /bins/{bin_id}/ack
Content-Type: application/json
```

```json
{
  "command_id": 42,
  "success": true,
  "pico_state": "LINE_FOLLOWING"
}
```

Bei Fehler:

```json
{
  "command_id": 42,
  "success": false,
  "error": "unsupported action: open_lid"
}
```

### 4. Bridge meldet Pico-Telemetrie

```http
POST /bins/{bin_id}/telemetry
Content-Type: application/json
```

Minimal:

```json
{
  "pico_state": "STANDBY"
}
```

Optional später:

```json
{
  "pico_state": "LINE_FOLLOWING",
  "fill_level": 87,
  "battery": 64,
  "deckel_offen": false,
  "target_destination": "STREET",
  "line_position": 12,
  "obstacle_cm": 48.5
}
```

Backend-Mapping:

| `pico_state` | Dashboard-Status |
|---|---|
| `STANDBY`, `FULL`, `USER_PAUSED` | `idle` |
| `LINE_FOLLOWING`, `LINE_LOST`, `OBSTACLE`, `ARRIVED` | `en_route` |
| `WAIT_AT_STREET` | `idle` |
| `EMPTIED` | `emptied` |

`FULL` setzt den Füllstand mindestens auf `95`, `EMPTIED` setzt ihn auf `0`,
falls kein expliziter `fill_level` mitgesendet wird.

---

## Test-Commands

Command in Backend-Queue legen:

```bash
curl -X POST http://localhost:8000/bins/1/command \
  -H 'Content-Type: application/json' \
  -d '{"action":"goto_street"}'
```

Pico-Status simulieren:

```bash
nc localhost 50002
Pico ist bereit
STATUS:FULL
ACK CMD_GOTO_STREET
ARRIVED: STREET
```

---

## Architekturentscheidung

Für diesen Slice ist TCP kein Gegenentwurf zur Web-App, sondern ein Adapter:

- Der Pico bleibt lokal autonom und echtzeitnah.
- Die Bridge kapselt Transportdetails.
- FastAPI bleibt zentrale Wahrheit für Dashboard, Agent und Commands.
- Ein späterer Wechsel auf direkte HTTP-Polling-Firmware betrifft nur die
  Transport-Schicht, nicht die Flottenmanagement-App.

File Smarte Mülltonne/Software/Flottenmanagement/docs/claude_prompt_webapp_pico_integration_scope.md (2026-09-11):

# Claude-Code-Prompt: WebApp glätten und Pico-Integration vorbereiten

Du arbeitest im Repo der smarten Mülltonne:

```text
Smarte Mülltonne/Software/Flottenmanagement
```

Bitte lies zuerst diese beiden aktuellen Übergabedokumente:

```text
docs/webapp_edits_2026-06-19.md
docs/connection_notes_2026-06-19.md
```

## Ziel

Die WebApp soll als Leitstand für die smarte Mülltonne sauberer, bedienbarer und
integrationsbereit für den Pico/Touchpanel-Flow werden. Bitte keine große
Design-Neuerfindung und keine Marketing-Oberfläche bauen. Es ist eine operative
Dashboard-WebApp für Operatoren, nicht für Endverbraucher.

Die App soll weiterhin wie ein kompakter Leitstand wirken:

- dunkle UI als Basis,
- gelber Akzent passend zum Touchpanel,
- Karte im Zentrum,
- links die Flotte,
- rechts Chat/Status/Meldungen,
- keine Landingpage,
- keine dekorativen Karten-Layouts ohne Funktion.

## Relevante Dateien

Frontend:

```text
frontend/app/dashboard/page.tsx
frontend/app/dashboard/components/FleetPanel.tsx
frontend/app/dashboard/components/LeafletMap.tsx
frontend/app/dashboard/components/SecurityPanel.tsx
frontend/app/dashboard/components/ChatInterface.tsx
frontend/app/globals.css
frontend/types/index.ts
frontend/lib/labels.ts
```

Backend/Integration, falls nötig:

```text
backend/routers/commands.py
backend/routers/bins.py
backend/models/bin.py
backend/services/truck_simulator.py
backend/routers/ws.py
```

## Aufgabe 1: Detail-Popups/Karten für Mülltonnen-Pins verbessern

Aktuell sind die Popups beim Klick auf Mülltonnen-Pins sehr basic und schlecht
lesbar. Bitte überarbeite sie zu kompakten, gut lesbaren Detailkarten.

Inhalt pro Mülltonne:

- Name und Adresse
- Füllstand mit Prozent und visuellem Balken
- Akku mit Prozent
- Position/Zustand:
  - Zuhause
  - fährt zur Abholposition
  - an Abholposition
  - fährt nach Hause
  - unbekannt
- Sperrstatus
- aktuelle offene Meldung, falls vorhanden
- Home-/Pickup-Kontext, wenn vorhanden

Bitte beachten:

- Popup muss auf dunkler Karte gut lesbar sein.
- Kein übergroßes Modal.
- Kein Textüberlauf.
- Gute Touch-/Klickflächen.
- Stil an bestehende Leitstand-UI anpassen.

Falls Leaflet-Popups typografisch schwer zu stylen sind, nutze entweder sauber
gestyltes HTML im Popup oder eine eigene ausgewählte Detailkarte neben/über der
Karte. Wichtig ist: Klick auf Pin muss deutlich bessere Detailinformation zeigen.

## Aufgabe 2: FleetPanel interaktiv machen

Wenn im linken FleetPanel eine Tonne angeklickt wird, soll die Karte auf den
entsprechenden Pin zoomen bzw. panen.

Erwartetes Verhalten:

- Klick auf eine Tonne im FleetPanel selektiert diese Tonne.
- Karte zoomt/pannt auf die aktuelle Position der Tonne.
- Der Pin bzw. die Tonne wird visuell hervorgehoben.
- Optional: Popup/Detailkarte der Tonne automatisch öffnen.
- Die Selektion soll auch sichtbar im FleetPanel markiert sein.

Technischer Vorschlag:

- Selection-State in `dashboard/page.tsx` halten, z.B. `selectedBinId`.
- `FleetPanel` bekommt `selectedBinId` und `onSelectBin`.
- `LeafletMap` bekommt `selectedBinId` und steuert Pan/Zoom via `useMap`.
- Keine globale State-Library einführen.

Bitte auch berücksichtigen:

- Wenn Truck-Focus aktiv ist und eine Tonne gewählt wird, sollte Tonnen-Selektion
  priorisieren oder Truck-Focus deaktivieren. Bitte konsistentes UX-Verhalten
  wählen und kurz im Code/Commit-Kontext begründen.

## Aufgabe 3: Clickdummy "Neue Tonne hinzufügen" mit realistischem Pairing-Flow

Es soll eine Clickdummy-Funktion geben, um neue Tonnen hinzuzufügen. Wichtig:
Die WebApp ist kein Consumer-Onboarding, sondern ein Operator-Leitstand. Deshalb
soll der Flow technisch/operativ wirken, nicht wie eine Endkunden-App.

Bitte einen Button integrieren:

```text
Neue Tonne verbinden
```

Geeigneter Ort:

- im FleetPanel-Kopfbereich oder als kompakte Aktion in der Dashboard-Toolbar.

Der Button öffnet ein Menü/Modal/Panel mit einem realistischen Verbindungsprozess.

Vorgeschlagener Operator-Flow:

1. Gerät in Pairing-Modus setzen
   - Hinweistext: Pico/Touchpanel einschalten oder Setup-Modus starten.
   - Kein langer Consumer-Erklärungstext.
2. Gerät suchen
   - simulierte Suche mit Ladezustand.
   - beispielhaft gefundenes Gerät: `SmartBin Pico W`
   - Werte anzeigen: Signal, temporäre Geräte-ID, letzter Kontakt.
3. Gerät zuordnen
   - Name/Standort vergeben, z.B. `Westfalenweg 36`
   - optional Home-/Abholposition später auf Karte setzen.
4. Verbindung bestätigen
   - Zusammenfassung
   - Status: "bereit für Backend-Command-Queue"

Da dies erstmal Clickdummy ist:

- Noch keine echte Persistenz nötig, falls dadurch Scope klein bleibt.
- Optional kann lokal im UI ein temporärer Eintrag simuliert werden.
- Der Flow soll aber so gestaltet sein, dass später echte API-Endpunkte ergänzt
  werden können.

Bitte im Code klar trennen:

- UI-Step-State
- simulierte Device-Daten
- spätere API-Anschlussstellen

Keine komplizierte Wizard-Bibliothek hinzufügen.

## Aufgabe 4: Pico-Integration mitdenken

Bitte keine echte Pico-Firmware schreiben. Aber die WebApp soll so vorbereitet
sein, dass folgende echte Integration sauber möglich ist:

- Pico sendet Touchpanel-Events ans Backend:
  - `damage_report`
  - `hygiene_report`
  - `lock`
  - `unlock`
  - `lid_open`
  - `lid_close`
  - `goto_pickup`
  - `return_home`
  - `eco_mode`
  - `power_off`
- WebApp/Backend sendet Befehle über bestehende Command-Queue:
  - `POST /bins/{bin_id}/command`
  - `GET /bins/{bin_id}/pending-command`
  - `POST /bins/{bin_id}/ack`

Bitte prüfe, ob die UI-Begriffe und Statuslabels dazu passen. Falls Labels
fehlen, ergänze sie in `frontend/lib/labels.ts`.

## Nicht im Scope

Bitte nicht:

- komplettes Redesign der App,
- neue State-Management-Library,
- neue Backend-Architektur,
- echte WLAN-/Pico-Firmware,
- Login/Auth,
- Consumer-Onboarding,
- große Datenbankmigrationen ohne Not,
- Render-/Deployment-Umbau.

## Qualitätsanforderungen

- TypeScript sauber halten.
- Bestehende Komponentenstruktur respektieren.
- Kleine, fokussierte Änderungen.
- Keine unrelated Refactors.
- UI muss auf Desktop und kleineren Viewports nicht überlaufen.
- Popups/Buttons müssen gut lesbar sein.
- Build muss laufen.

Bitte am Ende ausführen:

```bash
cd "Smarte Mülltonne/Software/Flottenmanagement/frontend"
npm run build
```

Falls Backend geändert wird:

```bash
cd "Smarte Mülltonne/Software/Flottenmanagement/backend"
./.venv/bin/python -m compileall main.py routers services models
```

## Erwartetes Ergebnis

Am Ende bitte kurz dokumentieren:

- Welche Dateien geändert wurden.
- Wie die Pin-Detailansicht funktioniert.
- Wie FleetPanel -> Kartenfokus funktioniert.
- Wie der "Neue Tonne verbinden"-Clickdummy aufgebaut ist.
- Welche offenen echten Pico/API-Anschlussstellen bleiben.

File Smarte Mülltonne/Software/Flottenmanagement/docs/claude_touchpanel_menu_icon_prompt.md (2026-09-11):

# Claude Prompt: Touchpanel Hauptmenue-Tonnenicons ueberarbeiten

Du arbeitest im Repository der smarten Muelltonne 2.0. Ziel ist eine sehr
gezielte Ueberarbeitung der Touchpanel-Hauptmenues auf dem Pico-Display.

## Ausgangslage

Die Touchpanel-Firmware liegt hier:

```text
Smarte Mülltonne/Software/Flottenmanagement/firmware/pico_touchpanel/
```

Die beiden Hauptmenues werden als vorberechnete RLE-Bitmap-Assets angezeigt:

```text
firmware/pico_touchpanel/assets/menu_1.rle
firmware/pico_touchpanel/assets/menu_2.rle
```

Die aktuelle aktive Version ist ein Rollback auf den letzten guten Stand. Diese
Version ist geometrisch korrekt:

- Buttonpositionen passen.
- Buttongroessen passen.
- Zurueck-Pfeil passt.
- Seitenwechsel-Pfeile passen.
- Statuspunkte unten passen.
- Tonnen-Icons sitzen grundsaetzlich an der richtigen Stelle.
- Touchboxen und Navigation sollen nicht angefasst werden.

Wichtig: Die Datei `ui.py` soll fuer diesen Task normalerweise nicht geaendert
werden. Die sichtbaren Iconformen stecken in `menu_1.rle` und `menu_2.rle`.

## Unbedingt zuerst lesen

Lies vor der Umsetzung diese Doku:

```text
Smarte Mülltonne/Software/Flottenmanagement/docs/touchpanel_tonnenicon_design_notes.md
```

Darin stehen die Learnings aus dem letzten fehlgeschlagenen Versuch, der
Rollback-Stand und die Display-spezifischen Designentscheidungen.

## Ziel

Die Tonnen-Icons in den beiden Hauptmenues sollen auf dem echten Touchdisplay
sichtbar gefuellt wirken.

Aktuelles Problem:

- Die Tonnenkoerper haben fast dieselbe Farbe wie die Button-Hintergruende.
- Dadurch wirken die Tonnen im Hauptmenue teilweise ungefuellt.
- Sichtbar bleiben vor allem Deckel, gelbe Symbole und schwarze Kanten.
- Bei Lichteinstrahlung wird der Kontrast deutlich schlechter.

Gesucht ist kein neues Design, sondern eine vorsichtige Kontrastkorrektur.

## Was erhalten bleiben muss

Bitte unveraendert lassen:

- Layout der beiden Hauptmenues.
- Position und Groesse der Buttons.
- Position der Tonnen-Icons.
- Proportionen der Tonnen.
- Zurueck-Pfeil oben links.
- Pfeile zum Seitenwechsel.
- Statuspunkte unten.
- Gelbe Funktionssymbole.
- Schwarze/dunkle Raeder und Deckelkanten.
- Allgemeine Wireframe-Optik.

Die Formen waren vor dem letzten Experiment gut. Es geht nur darum, die
Tonnenkoerper klarer vom Button-Hintergrund abzusetzen.

## Was beim letzten Versuch falsch lief

Nicht wiederholen:

- grosse geometrische Flaechen ueber die Tonnen malen,
- Tonnenkoerper zu plakativ abdunkeln,
- Layer/Details der Tonne zerstoeren,
- Tonnen neu positionieren,
- Button-Hintergruende neu layouten,
- Gelb entsaettigen,
- die Wireframe-Anmutung durch flache Blockformen ersetzen.

Der letzte Ansatz, die RLEs per grobem Recoloring mit Masken zu uebermalen, hat
auf dem echten Display nicht funktioniert.

## Gewuenschter Ansatz

Arbeite minimalinvasiv:

1. Sichere vor jeder Aenderung den aktuellen Stand.
2. Nutze die aktive Rollback-Version als geometrische Basis.
3. Veraendere nur die Farbwerte der Tonnenkoerper bzw. ihrer direkten
   Koerper-Layer in `menu_1.rle` und `menu_2.rle`.
4. Der Tonnenkoerper soll etwas dunkler/neutraler als der Button-Hintergrund
   sein, aber nicht schwarz.
5. Seiten/Kanten duerfen minimal dunkler sein als die Hauptflaeche.
6. Das kleine helle Rechteck/Display vorne an der Tonne bleibt hell.
7. Deckel und gelbe Akzente bleiben in ihrer aktuellen Wirkung.

Falls moeglich, bevorzuge eine saubere Re-Export- oder palettebasierte
Recoloring-Loesung statt grobem Pixel-Uebermalen.

## Designrichtung

Das Touchpanel ist klein und zeigt feine Grauabstufungen schlecht.

Daher:

- keine subtilen Grau-auf-Grau-Unterschiede als alleinigen Kontrast verwenden,
- keine Verlaeufe als Hauptloesung,
- lieber wenige klare Tonwerte,
- Tonnenkoerper sichtbar gefuellt, aber weiterhin dezent,
- Gelb muss auf dem Display gut sichtbar bleiben.

Kontrastidee:

- Button: aktueller mittlerer blaugrauer Ton bleibt weitgehend.
- Tonnenkoerper: eine klar erkennbare Stufe dunkler als Button.
- Tonnenkanten/Seiten: noch eine kleine Stufe dunkler.
- Label/Touchpanel-Flaeche: hell.
- Funktionssymbol: gelb.

## Backup-Pflicht

Vor dem Bearbeiten ein Backup anlegen:

```text
firmware/pico_touchpanel/backups/YYYY-MM-DD_before_claude_menu_icon_rework/
```

Mindestens sichern:

```text
firmware/pico_touchpanel/assets/menu_1.rle
firmware/pico_touchpanel/assets/menu_2.rle
firmware/pico_touchpanel/ui.py
```

Es gibt bereits relevante Backups:

```text
firmware/pico_touchpanel/backups/2026-06-22_before_menu_contrast_fix/
firmware/pico_touchpanel/backups/2026-06-22_failed_menu_contrast_attempt/
```

Auf keinen Fall auf dem failed attempt aufbauen.

## Test auf dem Pico

Nach Aenderungen nur die beiden Menue-Assets auf den Pico kopieren und resetten:

```bash
fw="/ABSOLUTER/PFAD/ZU/firmware/pico_touchpanel"
python3 -m mpremote connect /dev/cu.usbmodemXXXX cp "$fw/assets/menu_1.rle" :/assets/menu_1.rle
python3 -m mpremote connect /dev/cu.usbmodemXXXX cp "$fw/assets/menu_2.rle" :/assets/menu_2.rle
python3 -m mpremote connect /dev/cu.usbmodemXXXX reset
```

Falls der Pico wie zuletzt verbunden ist, ist der Port wahrscheinlich:

```text
/dev/cu.usbmodem21101
```

Bitte trotzdem vorher kurz pruefen.

## Akzeptanzkriterien

Die Ueberarbeitung ist nur erfolgreich, wenn auf dem echten Display gilt:

- Die Tonnenkoerper wirken sichtbar gefuellt.
- Die Tonnen heben sich klarer vom Button-Hintergrund ab.
- Die Buttonpositionen und Iconpositionen sind unveraendert.
- Die Wireframe-Optik bleibt erhalten.
- Das Gelb bleibt gut lesbar.
- Kein neuer Pixelart-/8-Bit-Look entsteht.
- Bei Lichteinstrahlung ist die Menuefunktion besser erkennbar als vorher.

## Ergebnis bitte dokumentieren

Am Ende kurz dokumentieren:

- Welche Dateien geaendert wurden.
- Welche Farb-/Palettewerte angepasst wurden.
- Welches Backup angelegt wurde.
- Ob auf dem Pico getestet wurde.
- Was auf dem echten Display beobachtet wurde.

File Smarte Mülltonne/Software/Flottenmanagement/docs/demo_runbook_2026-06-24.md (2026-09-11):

# Demo-Runbook 2026-06-24

Stand: Testtag 2026-06-24, FH Soest.

Ziel: Web-App, FastAPI-Backend, TCP-Bridge und Pico arbeiten ueber dasselbe
Demo-Netz zusammen. Die Web-App schreibt Hardware-Kommandos in die Backend-Queue,
die TCP-Bridge holt sie dort ab und der Pico quittiert sie sichtbar per LED.

## Ergebnis des heutigen End-to-End-Tests

Der komplette Pfad funktioniert:

```text
Dashboard Hardware-Button
-> POST /bins/22/command
-> Backend-Queue
-> TCP-Bridge pollt /bins/22/pending-command
-> Pico bekommt CMD_*
-> Pico sendet ACK/STATUS/ARRIVED
-> TCP-Bridge postet /bins/22/ack und /bins/22/telemetry
-> Dashboard/Backend sehen den quittierten Zustand
```

Verifizierte Signale:

- Pico verbindet sich im Demo-WLAN mit `192.168.50.102`.
- Mac/Ethernet im Demo-Netz ist `192.168.50.10`.
- NanoRouter/Demo-Gateway ist `192.168.50.1`.
- Backend laeuft auf `127.0.0.1:8000`.
- TCP-Bridge lauscht auf `0.0.0.0:50002`.
- Test-Tonne fuer FH Campus ist `bin_id=22`.
- Klick auf Hardware-Buttons in der Web-App loest LED-Flackern am Test-Pico aus.
- `command-history` zeigt neue Commands mit gesetztem `ack_at`.

Beispiel fuer einen erfolgreichen Backend-Nachweis:

```text
[
  {"action":"goto_street","bin_id":22,"id":6,"ack_at":"2026-06-24T13:42:36.114060"},
  {"action":"goto_street","bin_id":22,"id":5,"ack_at":"2026-06-24T13:42:20.980394"},
  {"action":"goto_street","bin_id":22,"id":4,"ack_at":"2026-06-24T13:41:00.350071"}
]
```

## Netzwerk-Aufbau

Heute stabiler Demo-Aufbau:

```text
FH-WLAN / Internet
  Mac WLAN en0, z.B. 10.119.x.x

Privates Demo-Netz
  TP-Link TL-WR802N / SmartBinDemo
  Router-IP: 192.168.50.1
  Mac Ethernet: 192.168.50.10
  Pico WLAN: 192.168.50.102
```

Wichtig:

- Das Pico/Bridge-Netz braucht keinen Internetzugang.
- Der Mac darf gleichzeitig im FH-WLAN bleiben.
- Ethernet zum NanoRouter sollte keine Default-Route bekommen, damit das FH-WLAN
  weiterhin Internet liefert.
- WISP-Uplink zum FH-WLAN ist fuer den Pico-Test nicht noetig.

## TP-Link TL-WR802N Settings

Bewaehrte Demo-Einstellungen:

- Operation Mode: `WISP`
- Interne AP-SSID: `SmartBinDemo`
- Interner AP-Key: `SmartBin2026!`
- LAN-IP des TP-Link: `192.168.50.1`
- DHCP im Demo-Netz aktiv, damit Pico eine Adresse wie `192.168.50.102` bekommt.

Im TP-Link-Webinterface bedeutet:

- `Client Setting` / `SSID(to be bridged)` ist das externe WLAN, das der TP-Link
  als WISP-Client nutzen wuerde.
- `AP Setting` / `Wireless Network Name` ist das interne Demo-WLAN, in das sich
  Pico und ggf. weitere Demo-Geraete einloggen.

Fuer unseren heutigen lokalen Demo-Pfad ist entscheidend: Pico und Mac muessen im
internen `SmartBinDemo`-Netz sein. Der WISP-Uplink darf auch noch fehlen.

## Mac-Netz pruefen

WLAN-IP:

```bash
ipconfig getifaddr en0
```

Ethernet-IP, Interface kann je nach Adapter anders heissen:

```bash
ipconfig getifaddr en12
ipconfig getifaddr en11
ipconfig getifaddr en10
```

Default Route pruefen:

```bash
route -n get default | grep interface
```

Erwartung:

- Default Interface bleibt WLAN, z.B. `en0`.
- Ethernet hat die statische Demo-IP `192.168.50.10`.
- Router/Gateway auf Ethernet moeglichst leer lassen. Wenn macOS meckert, darf
  der Router auf `192.168.50.1` stehen, aber die Default Route sollte weiter
  ueber WLAN laufen.

## Terminal-Aufteilung fuer die Demo

Am wenigsten verwirrend sind vier feste Terminal-Fenster:

1. Backend
2. TCP-Bridge
3. Frontend/Web-App
4. Pico/mpremote

Nichts in diesen Fenstern schliessen, solange die Demo laeuft.

## Terminal 1: Backend starten

```bash
cd "/Users/jonaswiesner/Documents/GitHub/Interdisziplinäres Projekt: Smarte Mülltonne 2.0/Smarte Mülltonne/Software/Flottenmanagement/backend"
.venv/bin/uvicorn main:app --host 0.0.0.0 --port 8000
```

Healthcheck in einem zusaetzlichen Terminal:

```bash
curl http://127.0.0.1:8000/health
```

Erwartet:

```text
{"status":"ok"}
```

## Terminal 2: TCP-Bridge starten

Wichtig: Fuer die FH-Campus-Tonne `--bin-id 22` verwenden.

```bash
cd "/Users/jonaswiesner/Documents/GitHub/Interdisziplinäres Projekt: Smarte Mülltonne 2.0/Smarte Mülltonne/Software/Flottenmanagement"
python bridge/tcp_bridge.py --host 0.0.0.0 --port 50002 --bin-id 22 --backend http://127.0.0.1:8000
```

Erwartete Bridge-Logs:

```text
TCP bridge listening on ('0.0.0.0', 50002); backend=http://127.0.0.1:8000 bin_id=22
Pico connected from ('192.168.50.102', ...)
pico: Pico ist bereit
pico: STATUS:STANDBY
```

## Terminal 3: Web-App starten

Für eine stabile Vorführung:

```bash
cd "/Users/jonaswiesner/Documents/GitHub/Interdisziplinäres Projekt: Smarte Mülltonne 2.0/Smarte Mülltonne/Software/Flottenmanagement/frontend"
npm run demo
```

Das baut die Web-App statisch und serviert den `out`-Ordner auf Port `3000`.
Falls die App plötzlich ungestylt aussieht, läuft sehr wahrscheinlich ein
staler Next-Dev-Server oder das CSS-Asset wurde nicht geladen. Dann Port `3000`
beenden, `.next` löschen und `npm run demo` neu starten.

Für Entwicklung mit Hot Reload:

```bash
cd "/Users/jonaswiesner/Documents/GitHub/Interdisziplinäres Projekt: Smarte Mülltonne 2.0/Smarte Mülltonne/Software/Flottenmanagement/frontend"
npm run dev -- --hostname 0.0.0.0 --port 3000
```

Browser:

```text
http://127.0.0.1:3000/dashboard
```

Nicht `0.0.0.0` im Browser oeffnen. `0.0.0.0` ist nur die Server-Bind-Adresse.

Falls Port 3000 belegt ist:

```bash
npm run dev -- --hostname 0.0.0.0 --port 3001
```

Dann:

```text
http://127.0.0.1:3001/dashboard
```

## Terminal 4: Test-Pico starten

Testdatei:

```text
Smarte Mülltonne/Software/Flottenmanagement/firmware/pico_touchpanel/bridge_command_led_test.py
```

Start:

```bash
cd "/Users/jonaswiesner/Documents/GitHub/Interdisziplinäres Projekt: Smarte Mülltonne 2.0"
python -m mpremote connect /dev/cu.usbmodem214301 run "Smarte Mülltonne/Software/Flottenmanagement/firmware/pico_touchpanel/bridge_command_led_test.py"
```

Der USB-Port kann anders heissen. Suchen mit:

```bash
ls /dev/cu.usbmodem*
```

Erwartete Pico-Ausgabe:

```text
Wi-Fi connected: ('192.168.50.102', '255.255.255.0', '192.168.50.1', '192.168.50.1')
Connecting bridge: 192.168.50.10 50002
pico -> Pico ist bereit
pico -> STATUS:STANDBY
Bridge connected. Waiting for CMD_*.
```

## Web-App-Test

1. Dashboard oeffnen.
2. Tonne `FH Campus` / `bin_id=22` auswaehlen.
3. Hardware-Button `Abholung` klicken.
4. Am Pico muss die LED sichtbar flackern.
5. Bridge muss `CMD_GOTO_STREET` loggen.
6. `command-history` muss einen neuen Eintrag mit `ack_at` zeigen.

Check per curl:

```bash
curl http://127.0.0.1:8000/bins/22/command-history
```

Ein direkter Command ohne Web-App:

```bash
curl -X POST http://127.0.0.1:8000/bins/22/command \
  -H "Content-Type: application/json" \
  -d '{"action":"goto_street"}'
```

## Admin-Reset für wiederholbare Demo-Zustände

Für mehrere Demo-Durchläufe gibt es einen schlanken Admin-Bereich:

```text
http://127.0.0.1:3000/admin
```

Dort können alle Tonnenwerte auf Knopfdruck neu gesetzt werden:

- `Schichtbeginn`: realistischer Startzustand mit gemischten Füllständen
- `FH-Fokus`: FH-Campus-Tonne voll, passend für Hardwaretests mit `bin_id=22`
- `Hohe Auslastung`: viele volle Tonnen, gut für Routen- und Kapazitätsdemo
- `Ruhiger Tag`: wenige Abholungen, gut für Basischecks
- `Zufallswerte`: alle Tonnen neu würfeln

Der Admin-Bereich kann außerdem Routen, offene Meldungen und alte Hardware-Befehle
löschen, eine Simulationsgeschwindigkeit setzen und die Simulation bei Bedarf
pausiert starten. Über das Seed-Feld lässt sich ein zufälliger Zustand exakt
wiederholen.

Direkter Backend-Call, falls die Web-App nicht offen ist:

```bash
curl -X POST http://127.0.0.1:8000/admin/demo/reset \
  -H "Content-Type: application/json" \
  -d '{"profile":"hardware_focus","seed":22,"clear_history":true,"include_alerts":false,"sim_speed":1,"sim_paused":false}'
```

## Einführung für den Operator

Die Web-App hat eine kurze Leitstand-Einführung für den Müllwagen-Operator:

- startet beim ersten Dashboard-Besuch automatisch
- kann über den Header-Button `Einführung` jederzeit erneut geöffnet werden
- führt durch Leitstand, Routenplanung, Flotte, Tonnenbefehle, Karte,
  Detail-Panels und Live-Status
- ist bewusst aus Sicht der Primärpersona Stefan Krüger formuliert:
  Müllwagenfahrer und Tour-Disponent, mit wenig Zeit für verschachtelte Menüs
- funktioniert lokal auf `localhost` genauso wie in einem späteren Deployment,
  weil der Zustand nur im Browser-`localStorage` gespeichert wird.
- Reset für einen erneuten Erstnutzungs-Test in der Browser-Konsole:
  `localStorage.removeItem("smart-bin-operator-tour-v1")`

Für eine Präsentation aus Nutzersicht:

1. Dashboard öffnen.
2. Optional `Einführung` klicken.
3. Durch die Tour gehen und die Rolle des Operators erklären.
4. Danach `FH Campus` auswählen und `Abholung` klicken.
5. LED-Flackern am Pico als Hardware-Nachweis zeigen.

## Button- und Command-Mapping

Frontend/Backend Action:

```text
goto_street
return_home
stop
```

Bridge uebersetzt fuer den Pico:

```text
goto_street  -> CMD_GOTO_STREET
goto_pickup  -> CMD_GOTO_STREET
goto_home    -> CMD_RETURN_HOME
return_home  -> CMD_RETURN_HOME
stop         -> CMD_STOP
```

Pico antwortet:

```text
ACK CMD_GOTO_STREET
STATUS:LINE_FOLLOWING
ARRIVED: STREET
STATUS:WAIT_AT_STREET
```

Die Bridge bestaetigt danach ans Backend:

```text
POST /bins/22/ack
POST /bins/22/telemetry
```

## Relevante Dateien

- TCP-Bridge:
  `Smarte Mülltonne/Software/Flottenmanagement/bridge/tcp_bridge.py`
- Laptop/Pico-Simulator:
  `Smarte Mülltonne/Software/Flottenmanagement/bridge/pico_tcp_simulator.py`
- Test-Pico mit LED-Signal:
  `Smarte Mülltonne/Software/Flottenmanagement/firmware/pico_touchpanel/bridge_command_led_test.py`
- Einfacher Netzwerk-/LED-Test:
  `Smarte Mülltonne/Software/Flottenmanagement/firmware/pico_touchpanel/network_led_test.py`
- Touchpanel-Firmware Config:
  `Smarte Mülltonne/Software/Flottenmanagement/firmware/pico_touchpanel/config.py`
- Pico TCP Client fuer echte Touchpanel-Firmware:
  `Smarte Mülltonne/Software/Flottenmanagement/firmware/pico_touchpanel/tcp_bridge_client.py`
- Web-App API Helper:
  `Smarte Mülltonne/Software/Flottenmanagement/frontend/lib/api.ts`
- Dashboard-Hardware-Buttons:
  `Smarte Mülltonne/Software/Flottenmanagement/frontend/app/dashboard/components/FleetPanel.tsx`
- Operator-Einführung:
  `Smarte Mülltonne/Software/Flottenmanagement/frontend/app/dashboard/components/OperatorTour.tsx`
- Admin-Reset-Seite:
  `Smarte Mülltonne/Software/Flottenmanagement/frontend/app/admin/page.tsx`
- Admin-Reset-API:
  `Smarte Mülltonne/Software/Flottenmanagement/backend/routers/admin_demo.py`

## Fallback ohne echten Pico

Falls der Pico oder USB/Serial Stress macht, kann die Bridge gegen den lokalen
Simulator getestet werden:

```bash
cd "/Users/jonaswiesner/Documents/GitHub/Interdisziplinäres Projekt: Smarte Mülltonne 2.0/Smarte Mülltonne/Software/Flottenmanagement"
python bridge/pico_tcp_simulator.py --host 127.0.0.1 --port 50002 --arrival-delay 3
```

Dann Web-App wie oben bedienen. Der Simulator quittiert die Commands anstelle
des Picos.

## Troubleshooting

Backend-Port belegt:

```bash
lsof -iTCP:8000 -sTCP:LISTEN -n -P
kill <PID>
```

Pico-USB-Port durch anderes Terminal belegt:

```bash
lsof /dev/cu.usbmodem214301
kill <PID>
```

Bridge bekommt keinen Pico:

- Ist Pico im WLAN `SmartBinDemo`?
- Stimmt `BRIDGE_HOST = "192.168.50.10"` in der Testdatei/Firmware?
- Laeuft die Bridge auf `--host 0.0.0.0 --port 50002`?
- Hat der Mac auf Ethernet wirklich `192.168.50.10`?

Web-App laedt nicht:

- Frontend-Terminal offen lassen.
- URL `http://127.0.0.1:3000/dashboard` verwenden.
- Bei belegtem Port auf `3001` ausweichen.
- Backend-Healthcheck pruefen: `curl http://127.0.0.1:8000/health`.

Commands kommen nicht an:

- Bridge muss mit `--bin-id 22` laufen.
- In der Web-App muss `FH Campus` ausgewaehlt sein.
- `curl http://127.0.0.1:8000/bins/22/pending-command` pruefen.
- `curl http://127.0.0.1:8000/bins/22/command-history` pruefen.

## Merksatz

Backend legt Commands ab. Bridge holt Commands ab. Pico quittiert. Das Dashboard
ist nur die Bedienoberflaeche fuer denselben Backend-Briefkasten.

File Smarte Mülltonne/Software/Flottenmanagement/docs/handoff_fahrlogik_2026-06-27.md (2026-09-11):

# Übergabeprotokoll: Fahrlogik & Pico-Firmware (2026-06-27)

Dieses Dokument beschreibt den Stand der **autonomen Fahrlogik** der Smarten Mülltonne nach
der Testsession am 2026-06-27. Es dient als **Übergabe an weitere Entwickler:innen** und enthält:
was funktioniert, wie es funktioniert, wo man schraubt, bekannte Grenzen und der Betriebs-Runbook.

> TL;DR: Der **volle Fahrzyklus läuft in den Tests wie gewollt** — Hinfahrt zur Abholposition,
> Rückfahrt nach Hause inkl. zweier 180°-Drehungen, ausgelöst per Touchpanel **und** Web-App,
> mit funktionierendem Sofort-Stopp während der Fahrt.

> **Ergänzt am 2026-06-27 (Diagnose-Session):** Verifikation, dass die Pico-Firmware byte-identisch
> zum Repo ist (§1, §6.6), eine erfolgreich am Touch-Display ausgelöste Linienfahrt mit Sensor-Belegen
> (§4) sowie Serial-Debug-Workflow (§6.7) und neue Learnings (§7.10–7.12, v.a. „aufgebockt testen geht
> nicht").

---

## 1. Wichtig zuerst: Welcher Code läuft wirklich?

Es gibt im Repo **zwei parallele Code-Stacks**. Das ist die größte Stolperfalle bei der Übergabe.

| Stack | Pfad | Status |
|---|---|---|
| **Inline-Stack (LIVE auf dem Pico)** | `firmware/pico_touchpanel/main.py` | ✅ **Das ist der produktive Stand.** Eine einzige `main.py`, die Touchpanel-UI, Sensoren, Motoren, Bridge-Client und die komplette Fahrlogik inline enthält. |
| Modularer Stack | `../Quellcode/Client/` (`main.py`, `global_controller_test.py`, `network_*`) | ⚠️ **Läuft NICHT auf dem Pico.** State-Machine-Variante mit Hindernis-Umfahrung. Wurde getestet, aber wegen schlechterer Linienverfolgung (siehe §7) wieder verworfen. |

**Alle Änderungen dieser Session wurden im Inline-Stack `firmware/pico_touchpanel/main.py` gemacht.**
Wer an der Fahrlogik arbeitet, editiert diese Datei und flasht sie auf den Pico (§6).

> **Verifiziert am 2026-06-27 (Diagnose-Session):** Nach einem Rollback an der Motorlogik bestand die
> Sorge, die funktionierende Touch-Display-Firmware sei vom Pico verschwunden. Per `mpremote` ausgelesen
> und byteweise gegen `firmware/pico_touchpanel/` geprüft: **`main.py`, `ui.py`, `config.py`,
> `tcp_bridge_client.py` und alle 351 Assets sind byte-identisch zum Repo**; `display.py`, `touch.py`,
> `wireframe.py` unterscheiden sich nur in den Zeilenenden (CRLF auf dem Pico vs. LF im Repo — für
> MicroPython irrelevant). **Der Rollback hat nichts gelöscht.** Der Pico-Stand entspricht dem Repo.
> Wer „ist auf dem Pico wirklich der Repo-Code?" prüfen will, nutzt den Vergleich aus §6.6.

---
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

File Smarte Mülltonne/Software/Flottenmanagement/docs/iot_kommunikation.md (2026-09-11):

# IoT-Kommunikation — Tonne ↔ Server ↔ Dashboard

> **Zweck:** Vollständige, zeichnungsreife Beschreibung aller Kommunikationswege. Strukturiert für Excalidraw — Boxen für Akteure, beschriftete Pfeile für Protokoll + Takt.
>
> **Stand:** Mai 2026, entspricht dem echten Firmware-Code unter `Software/Quellcode/Client/` und der Bridge `Flottenmanagement/bridge/tcp_bridge.py`

---

## 0. Das Wichtigste zuerst

**Es gibt genau EINEN Pico in der Tonne.** Er macht alles:

- **Antrieb:** 2 DC-Motoren, 5 Liniensensoren, PD-Regler, 50-Hz-Fahrschleife
- **Sensoren:** Ultraschall-Füllstand, Ultraschall-Hindernis
- **Bedienung:** 2 Buttons (rot/grün), Buzzer, Status-LEDs
- **Netzwerk:** TCP-Socket-Client zum Server
- **Touchpanel (Ziel):** Das Display-UI ist aktuell ein separater Prototyp (`Flottenmanagement/firmware/pico_touchpanel/`), soll aber in dieselbe Firmware integriert werden — **derselbe Pico**, nicht ein zweiter.
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

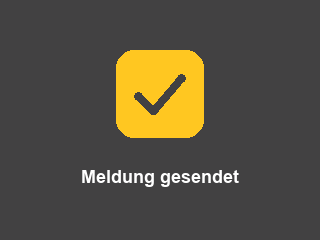
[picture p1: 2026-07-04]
Smarte Mülltonne/Software/Flottenmanagement/firmware/pico_touchpanel/tools/confirm_report.png

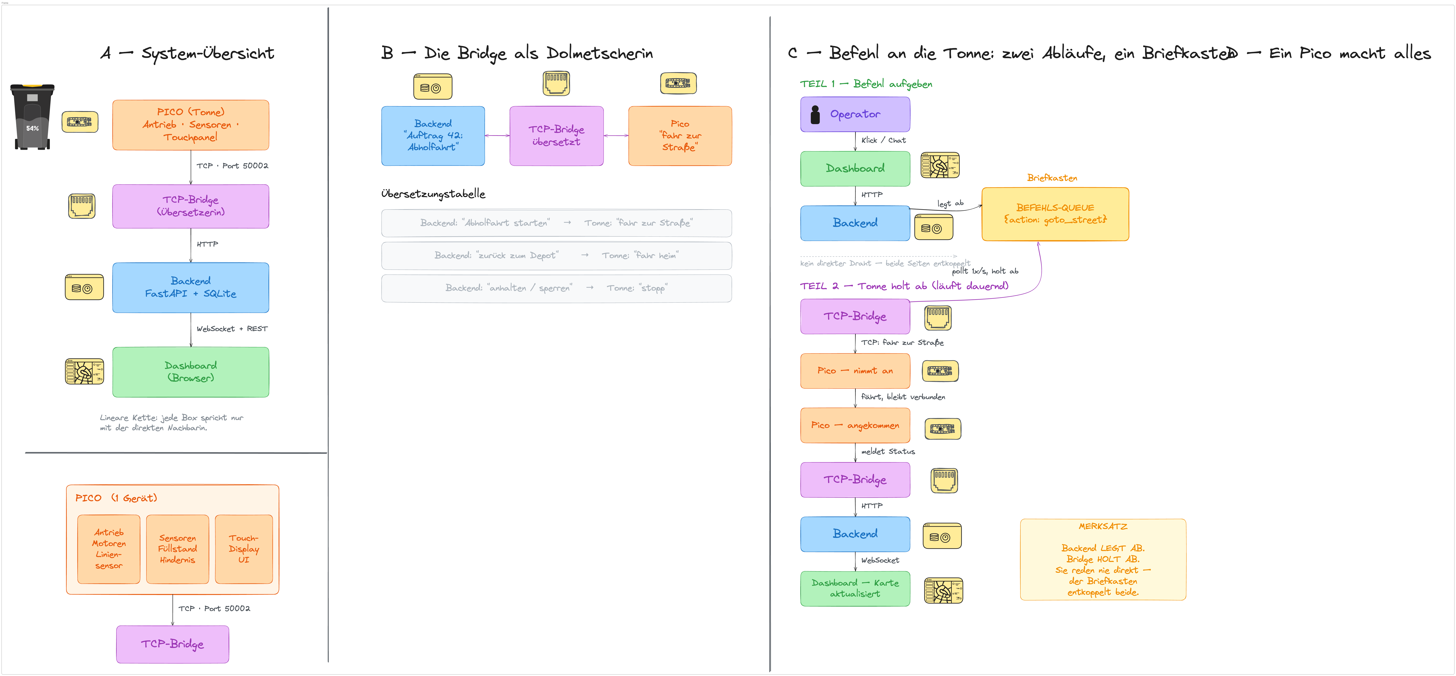
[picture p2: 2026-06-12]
Smarte Mülltonne/Software/Flottenmanagement/docs/Unbenannt-2026-03-25-1250.excalidraw.png

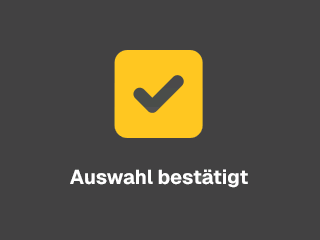
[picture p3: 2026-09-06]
Smarte Mülltonne/Software/Flottenmanagement/firmware/pico_touchpanel/tools/confirm_generic_ref.png

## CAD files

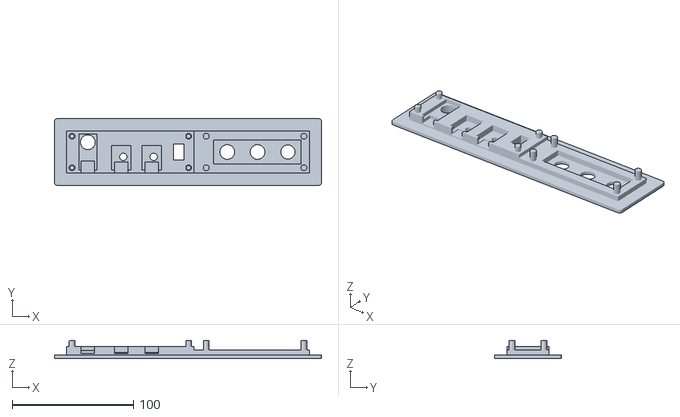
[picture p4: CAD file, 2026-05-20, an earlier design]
Smarte Mülltonne/Alt/Bauteile/STL-Datein/Anzeige.stl-neu.stl
220.0 x 55.0 x 15.0

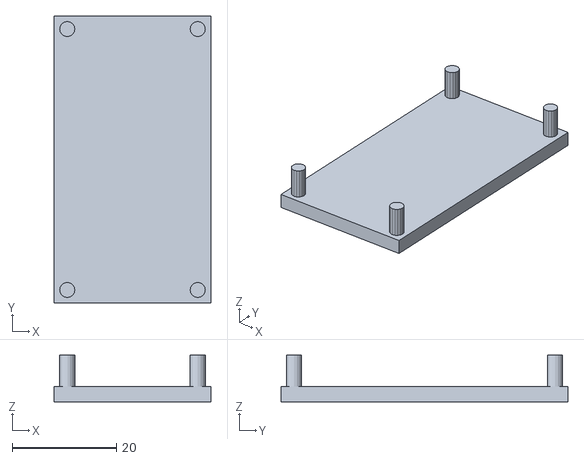
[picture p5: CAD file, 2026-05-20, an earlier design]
Smarte Mülltonne/Alt/Bauteile/STL-Datein/Deckel Ultraschallsensor.stl
30.0 x 55.0 x 9.00

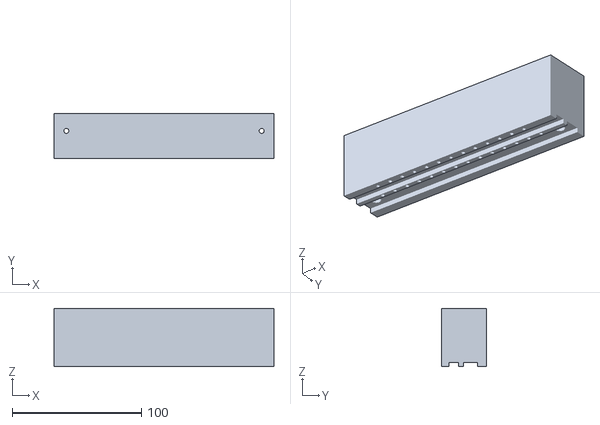
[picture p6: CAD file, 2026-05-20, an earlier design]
Smarte Mülltonne/Alt/Bauteile/STL-Datein/Sensorhalter.stl
170.0 x 35.0 x 45.0

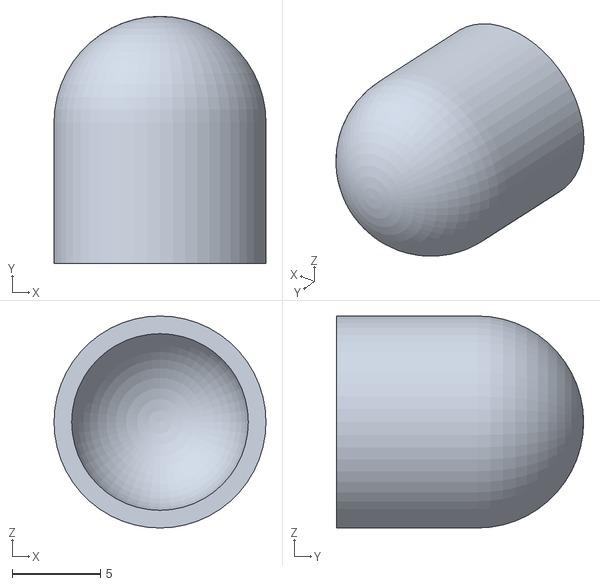
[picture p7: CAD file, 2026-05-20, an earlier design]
Smarte Mülltonne/Alt/Bauteile/STL-Datein/haube.stl
12.0 x 14.0 x 12.0

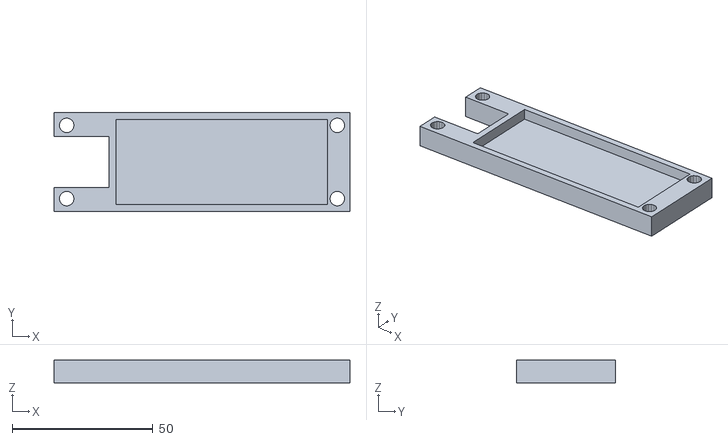
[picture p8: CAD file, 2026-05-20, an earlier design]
Smarte Mülltonne/Alt/Bauteile/STL-Datein/Deckel Anzeige neu.stl
105.0 x 35.0 x 8.00

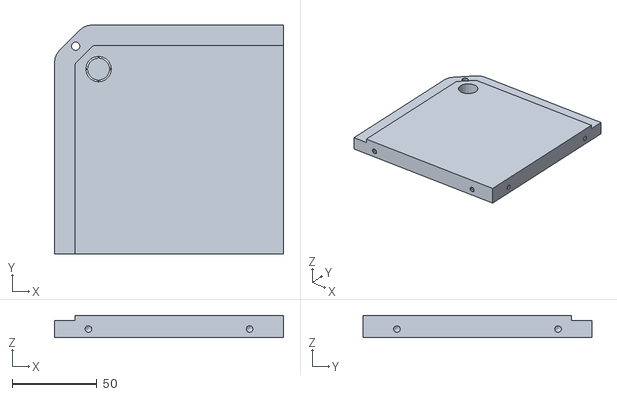
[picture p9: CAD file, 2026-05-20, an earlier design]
Smarte Mülltonne/Alt/Bauteile/STL-Datein/Deckel variante2.stl
135.0 x 135.0 x 13.0

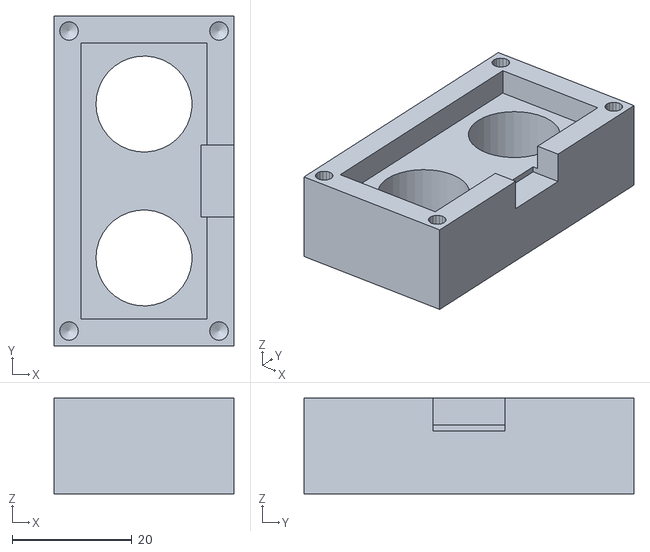
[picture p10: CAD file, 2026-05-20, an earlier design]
Smarte Mülltonne/Alt/Bauteile/STL-Datein/Gehäuse Ultraschallsensor.stl
30.0 x 55.0 x 16.0

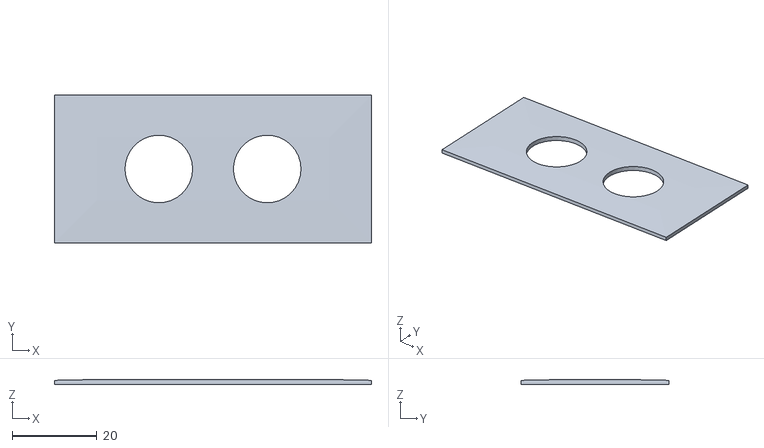
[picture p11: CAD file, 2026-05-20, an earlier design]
Smarte Mülltonne/Alt/Bauteile/STL-Datein/Abdeckung.stl
75.0 x 35.0 x 1.20

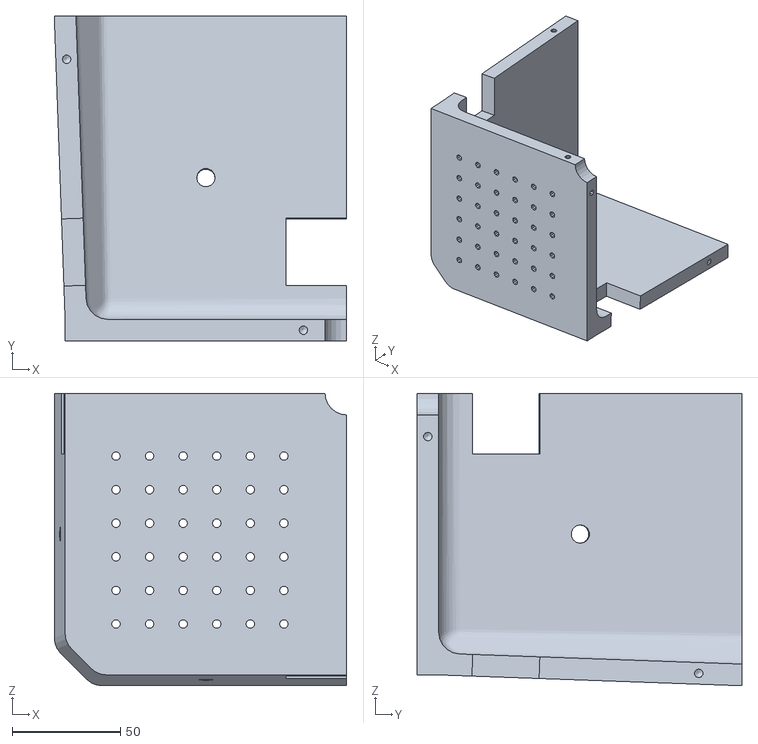
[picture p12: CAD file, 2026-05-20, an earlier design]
Smarte Mülltonne/Alt/Bauteile/STL-Datein/Mülltonenboden Variante 2.stl
135.0 x 150.0 x 135.0

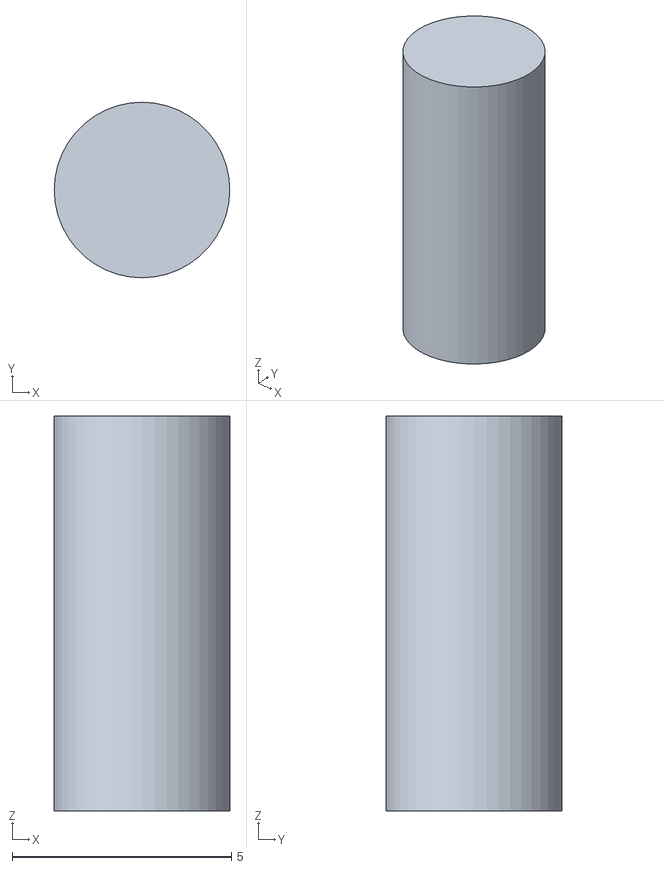
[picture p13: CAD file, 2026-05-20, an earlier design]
Smarte Mülltonne/Alt/Bauteile/STL-Datein/Stifte.stl
4.00 x 4.00 x 9.00

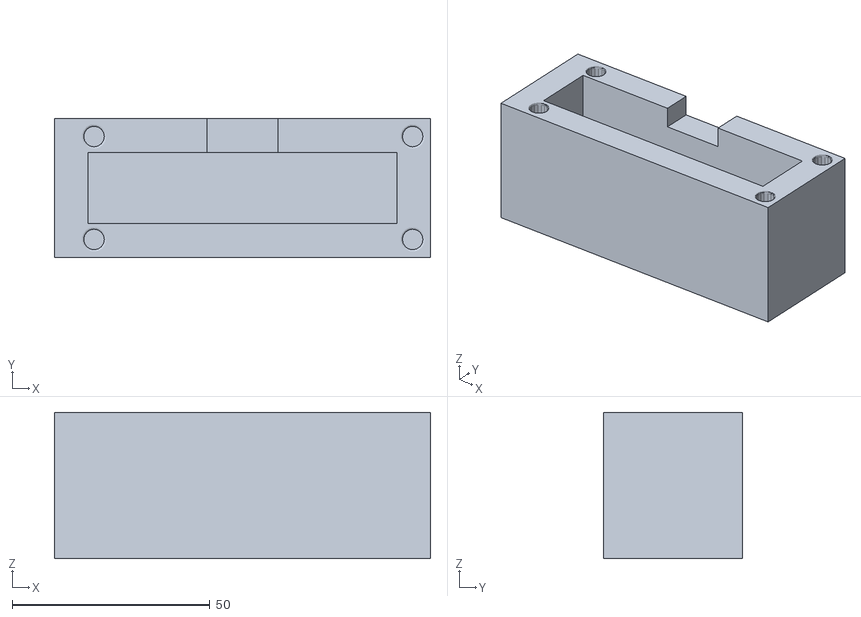
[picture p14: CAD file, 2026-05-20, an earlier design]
Smarte Mülltonne/Alt/Bauteile/STL-Datein/Deckel_Stecker.stl
95.0 x 35.0 x 37.0

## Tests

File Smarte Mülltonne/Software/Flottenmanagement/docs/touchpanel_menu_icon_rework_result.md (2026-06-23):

# Touchpanel Hauptmenue-Tonnenicons: Ergebnis Kontrastkorrektur

Stand: 2026-06-22

Umsetzung des Tasks aus `claude_touchpanel_menu_icon_prompt.md` unter Beachtung
von `touchpanel_tonnenicon_design_notes.md`.

## Befund (vor der Aenderung)

Die RLE-Assets sind palettenbasiert (`WF1`-Header: width, height, Palette,
danach pro Zeile `(run, palette_index)`-Paare). Analyse der aktiven
Rollback-Version `menu_1.rle` / `menu_2.rle`:

- Jeder Button ist ein zweifarbiges Rechteck: obere Bande hellgrau
  (`#7B7D7B`, ~123) und untere Bande etwas dunkler (`#6A6D6A`, ~106),
  Trennkante in Buttonmitte.
- Das Tonnen-Icon (Deckel, gelbes Funktionssymbol, helles Label, dunkle Fuesse)
  liegt darueber.
- **Es gibt gar keinen gefuellten Tonnenkoerper.** Der Bereich zwischen Deckel
  und Fuessen ist reiner Button-Hintergrund. Deshalb wirkte die Tonne
  ungefuellt — nicht weil der Koerper "fast dieselbe Farbe" wie der Button hat,
  sondern weil schlicht keine Koerperflaeche existiert.

## Loesungsansatz

Reine Paletten-/Pixel-Recolor-Loesung, kein Verschieben von Geometrie:

- Als geometrische Basis dient die aktive Rollback-Version (identisch mit
  `backups/2026-06-22_before_menu_contrast_fix/`).
- Aus dem fehlgeschlagenen Versuch
  (`backups/2026-06-22_failed_menu_contrast_attempt/`) wurde **ausschliesslich
  die saubere Koerper-Maske** (welche Pixel zur Tonnenkoerper-Trapezflaeche
  gehoeren) als Referenz uebernommen. Diese Maske beruehrt nur ehemalige
  Button-Hintergrundpixel — Deckel, Label, Gelb und Fuesse bleiben unberuehrt.
- Inhaltlich wurde **nicht** auf dem Failed-Attempt aufgebaut: dessen Fehler war
  der nahezu schwarze, plakative Fuellton. Es wurde nur die Koerperflaeche
  uebernommen und mit einem dezenten Ton neu gefuellt.

Der Koerper erhaelt eine 3-stufige Wireframe-Schattierung (statt eines flachen
Blocks):

| Layer | RGB888 | RGB565 | Zweck |
|---|---|---|---|
| Koerper hell | (96, 98, 96)  | 0x630C | obere Koerperkante, leichtes Volumen |
| Koerper Hauptton | (72, 74, 72)  | 0x4A49 | Hauptflaeche, eine klare Stufe < Button|
| Koerper Kante | (54, 56, 54)  | 0x39C7*  | Seiten/Silhouette, etwas dunkler |

\* `0x39C7` existierte bereits in beiden Paletten und wurde wiederverwendet.

Zum Vergleich: Button ~106/123. Der Hauptton 72 liegt eine klar erkennbare
Stufe darunter, bleibt aber deutlich heller als der nahezu schwarze
Failed-Ton (~49/56/57) und als Deckel/Fuesse (~24). Gelb, Label und Deckel sind
unveraendert.

## Geaenderte Dateien

- `firmware/pico_touchpanel/assets/menu_1.rle`
  (Palette 28 -> 30 Eintraege, 5219 Koerperpixel umgefaerbt)
- `firmware/pico_touchpanel/assets/menu_2.rle`
  (Palette 31 -> 32 Eintraege, 4958 Koerperpixel umgefaerbt)

`ui.py` wurde nicht geaendert. Layout, Buttonpositionen, Iconpositionen,
Proportionen, Pfeile, Statuspunkte und Touchboxen bleiben unangetastet.

## Backup

Vor der Aenderung angelegt:

```text
firmware/pico_touchpanel/backups/2026-06-22_before_claude_menu_icon_rework/
  menu_1.rle
  menu_2.rle
  ui.py
```

## Test auf dem Pico

- Pico verbunden an `/dev/cu.usbmodem21101`.
- `menu_1.rle` und `menu_2.rle` per `mpremote` nach `:/assets/` kopiert.
- `mpremote ... reset` ausgefuehrt — erfolgreich.

## Ergebnis am echten Display: ABGELEHNT, zurueckgerollt

Bewertung am echten Touchpanel (2026-06-22):

- Die gefuellten Trapez-Koerper (Kandidat B) wirkten auf dem Panel wie
  **"fette Boxen", die ueber die eigentliche Form gelagert sind**. Die feine
  Wireframe-Anmutung ging verloren — derselbe Grundfehler wie beim frueheren
  Failed-Attempt, nur weniger dunkel.
- Auf Wunsch wurde **vollstaendig auf die gute Rollback-Version zurueckgerollt**
  (lokal + Pico, `mpremote cp` + `reset`).
- Aktiver Stand wieder Hash `2070df…cfbd6` / `beae13…38235`
  (== `2026-06-22_before_menu_contrast_fix`).

## Wichtige Learnings fuer den naechsten Versuch

1. **Das Panel rendert stark blaustichig.** Neutrale Palette-Grautoene
   erscheinen als Blau. Klar lesbar bleiben nur sehr dunkle Toene
   (Deckel ~ schwarz), Gelb und das helle Label. Grau-auf-Grau-Kontrast ist
   praktisch wertlos — entscheidend ist der **Helligkeitsabstand (Value)**.
2. **Eine gefuellte Trapezflaeche ist der falsche Weg.** Sowohl der dunkle
   Failed-Versuch als auch der dezentere Kandidat B wurden abgelehnt, weil eine
   geschlossene Koerperflaeche ueber der filigranen Wireframe-Form als plumpe
   Box wahrgenommen wird. Die Akzeptanz haengt nicht an der Tonwahl, sondern an
   der **Idee "Flaeche fuellen" selbst**.
3. **Im Rollback existiert gar kein Koerper-Layer.** Die Tonne besteht nur aus
   Deckelbalken, hellem Label, gelbem Symbol und Fuessen; der Rumpf ist leerer
   Button-Hintergrund. "Koerper sichtbar fuellen" und "Wireframe-Form behalten"
   stehen damit in direktem Konflikt.
4. **Moeglicher naechster Ansatz statt Flaechenfuellung:** nur eine duenne,
   klar dunkle **Kontur/Silhouette** des Tonnenrumpfes ziehen (Linien, kein
   Fill) — analog zu Deckel und Fuessen, die auf dem Panel gut lesbar sind. So
   bekaeme die Tonne eine erkennbare Begrenzung, ohne als gefuellte Box zu
   wirken. Vor Umsetzung mit dem Nutzer abstimmen.

Render-/Simulationsvergleiche (inkl. Blaustich-Simulation) lagen unter
`/tmp/menu_dbg/` vor. Backup der gefuellten Variante existiert nicht separat;
sie ist aus Rollback + Maske jederzeit reproduzierbar.

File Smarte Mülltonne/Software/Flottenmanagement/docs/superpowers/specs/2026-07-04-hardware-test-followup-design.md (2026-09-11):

# Spec: Hardware-Test Follow-up (2026-07-04)

Sammel-Spec für die Fixes/Verbesserungen, die beim Hardware-Testlauf am
physischen Pico aufgefallen sind (Testkatalog `hardwaretestkatalog_2026-07-04.md`).
Sechs unabhängige Punkte über Backend, Frontend und Firmware.

## Kontext / Betroffene Komponenten

- **Backend** (`Flottenmanagement/backend`): FastAPI, SQLAlchemy/SQLite.
- **Frontend** (`Flottenmanagement/frontend`): Next.js Leitstand (`app/dashboard`).
- **Firmware** (`Quellcode/Client` = laufender Stack, `Flottenmanagement/firmware/pico_touchpanel/ui.py` = laufende UI).

Reihenfolge: **A+B (Web, per pytest/Preview testbar)** → **D (Firmware Diagnose-Werte)**
→ **E+F (Hardware-Kalibrierung am Pico, gemeinsame Session)**. (C reklassifiziert →
in E aufgegangen.)

---

## A — Security: Quittieren pro Meldung

**Problem:** Quittiert der Operator eine Meldung, verschwinden **alle** offenen
Meldungen derselben Tonne mit.

**Ursache:**
- `routers/security.py:68` `resolve_events(bin_id)` setzt **alle** offenen Events
  der Tonne auf `resolved=True`.
- `SecurityPanel.tsx:78` ruft `onResolve(e.bin_id)` — also pro Tonne, nicht pro Event.

**Design:**
- Backend: neuer Endpoint `POST /security/events/{event_id}/resolve` → setzt genau
  dieses Event auf `resolved=True`; `404` wenn nicht gefunden. Rückgabe
  `{event_id, resolved: true}`.
- Der bestehende `POST /security/{bin_id}/resolve` bleibt erhalten (Bulk-Auflösung,
  z.B. bei Service/Entsperren), wird vom Button aber nicht mehr benutzt.
- Frontend: `SecurityPanel` Prop `onResolve(eventId: number)`, Button ruft
  `onResolve(e.id)`; Dashboard-Handler postet an den Event-Endpoint. Types anpassen.

**Betroffene Dateien:** `backend/routers/security.py`,
`frontend/app/dashboard/components/SecurityPanel.tsx`,
`frontend/app/dashboard/page.tsx`, `frontend/types` (Prop/Signatur).

**Akzeptanz / Test:** `backend/test_reports.py` erweitern: zwei Events auf Tonne 22
(hygiene + damage) anlegen, eines quittieren → das andere bleibt offen.

---

## B — Zeitzonen-Fix (Backend UTC-aware)

**Problem:** Im Leitstand angezeigte Zeiten liegen 2 h neben der lokalen Zeit (CEST).

**Ursache:** Timestamps werden als **naives UTC** ohne Zeitzonen-Kennung serialisiert
(z.B. `last_seen: "2026-07-04T13:30:29"`, kein `Z`). `security.py:31` speichert zwar
`datetime.now(timezone.utc)`, aber die SQLite-`DateTime`-Spalte legt naiv ab und
Pydantic/ORM gibt den Wert ohne Offset aus. Das Frontend
(`SecurityPanel.tsx:62` `new Date(e.timestamp).toLocaleString("de-DE")`)
interpretiert den offset-losen String als lokal → 2 h Versatz.

**Design (Backend UTC-aware):**
- Pydantic-Response-Schema `SecurityEventOut` mit Field-Serializer, der `timestamp`
  als UTC-aware ISO-8601 mit `Z` ausgibt (Endpoints geben aktuell rohe ORM-Objekte
  zurück → `response_model` einführen).
- **Scope-Fokus (bei Plan-Erstellung verifiziert):** Nur `SecurityEvent.timestamp`.
  `Bin.last_seen` wird im echten Leitstand **nirgends als Uhrzeit** angezeigt (nur in
  `lib/demo.ts`-Mockdaten), daher **nicht** Teil des Fixes (kein `BinOut`-Umbau, YAGNI).
- Fixt beide Anzeigen: `SecurityPanel.tsx:62` und `AlertBanner.tsx:36` hängen beide
  an `event.timestamp`. Frontend bleibt unverändert (`toLocaleString` konvertiert
  dann korrekt nach CEST).

**Betroffene Dateien:** `backend/routers/security.py` (Response-Schema + `response_model`).

**Akzeptanz / Test:** Neuer Backend-Test: `GET /security/events` liefert
`timestamp`, der auf `Z`/`+00:00` endet; ein bekannter UTC-Wert erscheint nach
Frontend-Konvertierung als korrekte CEST-Zeit (manuell/Preview gegengeprüft).

---

## C — Diagnose-Panel: Zurück-Button — REKLASSIFIZIERT (kein eigener Task)

**ERRATUM (bei der Plan-Erstellung korrigiert):** Ursprünglich als Code-Bug
angenommen. Beim Nachlesen des exakten Codes zeigte sich: `draw_diagnose()`
(`ui.py:310`) setzt `self.buttons = [Button(92, 188, 136, 46, "menu_2")]` — die
Aktion `"menu_2"` **wird** in `handle_action()` behandelt (`→ SCREEN_MENU_2`).
**Kein Code-Bug.** (Der `confirm_back`-Button aus `ui.py:315` gehört zu
`draw_confirm`, nicht zum Diagnose-Panel.)

**Tatsächliche Ursache:** Der Button sitzt bei `y = 188…234`, also ganz **unten am
Bildschirmrand** (max 240). Beim beschriebenen Touch-Versatz („Boxen sitzen leicht
unter den Buttons") landet ein Tap dort bei `y ≈ 234–240+` → am/über dem Rand →
Fehltreffer. Damit ist dieser breite, aber randständige Button der am schlechtesten
treffbare. → **Symptom der Touch-Fehlkalibrierung, wird von Punkt E behoben.**

**Konsequenz:** Kein separater Task. Verifikation wandert in die Akzeptanz von E.

---

## D — Diagnose-Panel: Live-Werte (Füllstand %, Hindernis cm)

**Problem:** Das Diagnose-Panel zeigt keine dynamischen Werte; die Daten sind im
UI-Objekt vorhanden, werden aber nicht gerendert.

**Ursache:** `draw_diagnose()` (`ui.py:310`) zeichnet nur ein statisches Asset
(`diagnose_ok`/`diagnose_alert`). `obstacle_cm` (`ui.py:58`, gesetzt via
`set_status` `ui.py:83`) und `fill_level` werden dort nicht ausgegeben.

**Design:**
- `draw_diagnose()` überlagert das Basisbild mit zwei Textwerten: **Füllstand %**
  und **Hindernis cm** an definierten Positionen (Layout im Plan festlegen).
- Live-Refresh: in `tick()` bei `screen == SCREEN_DIAGNOSE` die beiden Felder neu
  zeichnen, wenn sich `fill_level`/`obstacle_cm` seit dem letzten Frame geändert
  haben — partielles Repaint (Rechteck hinter dem Text neu füllen, dann Text),
  analog `draw_fill_overlay()` (`ui.py:261`), kein Vollbild-Flackern.
- Feed-Kette verifizieren: Controller (`global_controller_test.py`) muss
  `obstacle_cm` und `fill_level` regelmäßig via `set_status` an die UI liefern.

**Betroffene Dateien:** `Flottenmanagement/firmware/pico_touchpanel/ui.py`,
ggf. `Quellcode/Client/global_controller_test.py` (Feed).

**Akzeptanz:** Bei geöffnetem Diagnose-Panel ändern sich Füllstand % und Hindernis cm
sichtbar, wenn sich die realen Sensorwerte ändern.

---

## E — Touch: 5-Punkt-Neukalibrierung

**Problem:** Touch-Treffer sitzen leicht **unter** den Buttons; Touch-Qualität
insgesamt schlecht.

**Ursache:** Kalibrierwerte (`config.py` `TOUCH_X/Y_MIN/MAX`, `SWAP/INVERT`) leicht
daneben → systematischer Y-Versatz. `read_raw()` (`touch.py`) macht eine
Einzelmessung ohne Mittelung (nicht Teil dieses Fixes — bewusst außen vor gelassen).

**Design (Hardware-in-the-loop, nur Neukalibrierung):**
- `touch_calibrate.py` per USB auf dem Pico laufen lassen (5 Zielkreuze:
  TOP_LEFT, TOP_RIGHT, BOTTOM_RIGHT, BOTTOM_LEFT, CENTER).
- Operator tippt die Kreuze; Rohwerte (`RESULT`-Zeilen) seriell mitlesen.
- Daraus neue `TOUCH_X_MIN/MAX`, `TOUCH_Y_MIN/MAX` berechnen; `SWAP_XY`/`INVERT_*`
  gegenprüfen. In `config.py` schreiben und reflashen.

**Betroffene Dateien:** `Quellcode/Client/config.py` (Kalibrierkonstanten).

**Akzeptanz:** Touch-Treffer decken sich mit den sichtbaren Buttons (kein
„sitzt drunter"); alle Menü-/PIN-Buttons zuverlässig bedienbar. **Inkl. Gegenprobe
Punkt C:** der Diagnose-Zurück-Button (unterster Button, `y=188…234`) trifft nach
der Kalibrierung zuverlässig. Falls er trotz sauberer Kalibrierung am Rand zickt →
Nachtrag: Button höher/größer setzen (`ui.py` `draw_diagnose`).

**Hinweis:** Erfordert USB + Operator am Panel. Fällt-back auf Offset-Korrektur/
Mehrfachmessung nur, falls die reine Neukalibrierung das Problem nicht löst
(dann Nachtrag im Spec).

---

## F — Party-Modus: Endlage = Startlage (zeitbasiert kalibriert)

**Problem:** Party-Modus dreht, endet aber nicht in der Startorientierung.

**Ursache:** `_logic_party()` (`global_controller_test.py:558`) dreht **open-loop
zeitbasiert**: PWM-Spin bei `party_speed=65` für `party_duration_ms`, berechnet aus
`steps_to_ms(rotation_steps, party_speed)` (`:253`) mit
`steps_to_ms = steps*1000/freq` (`steppermotor.py:188`). Die Step-Rechnung
(`rotation_steps = 2*44000*party_full_rotations` = N volle 360°-Drehungen) ist
korrekt, aber die zeitbasierte Ausführung zählt keine echten Schritte → Anlauf-
Rampe und Schrittverluste bei Tempo 65 lassen die Endlage driften.

**Design (zeitbasiert kalibrieren, kein Umbau auf Schrittzählung):**
- Logik bleibt: N volle Umdrehungen, `party_duration_ms` aus `steps_to_ms`.
- Am realen Aufbau `party_speed` und die 180°-Konstante (`turn_home_180_steps=44000`)
  einmessen, bis N Drehungen sauber am Start landen (ggf. `party_full_rotations`/
  Tempo anpassen, um Rampen-Drift zu minimieren).
- Konstanten in `global_controller_test.py` festschreiben.

**Betroffene Dateien:** `Quellcode/Client/global_controller_test.py`
(`party_speed`, `party_full_rotations`, `turn_home_180_steps`).

**Akzeptanz:** Nach Ablauf der Party-Sequenz zeigt die Tonne wieder in
Startrichtung (Rest-Drift innerhalb weniger Grad akzeptabel, open-loop).

---

## Nicht im Scope (YAGNI)

- Touch: Offset-Term, Mehrfachmessung/Entprellung, größere Hitboxen (nur falls
  Neukalibrierung E nicht reicht).
- Party: echter Umbau auf schrittgenaues Pulsen (`rotate_steps`).
- Füllstand-Sensor C8 / T2 (Sensor noch nicht verbaut) — separater Vorgang.
- Motor-Pin-Swap-Fix aus T1 ist bereits umgesetzt/geflasht (uncommitted), nicht Teil
  dieses Specs.

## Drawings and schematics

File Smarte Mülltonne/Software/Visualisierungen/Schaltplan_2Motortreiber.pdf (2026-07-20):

# Schaltplan

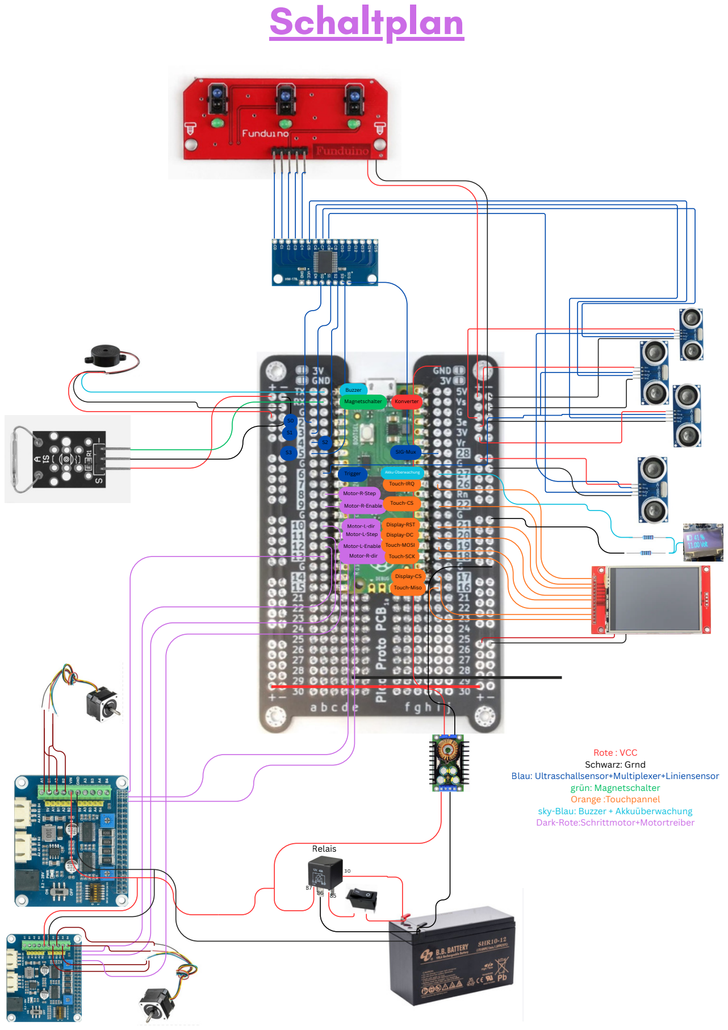
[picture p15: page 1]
Buzzer; Magnetschalter; Trigger; Motor-R-Step; Motor-R-Enable; Motor-L-dir Motor-L-Step; Motor-L-Enable; Motor-R-dir; Touch-SCK; Touch-MOSI; Display-DC; Display-RST; Touch-CS; Touch-IRQ; SIG-Mux; Konverter; Akku-Überwachung; Rote : VCC Schwarz: Grnd; grün: Magnetschalter Orange :Touchpannel

Display-CS
Touch-Miso

Blau: Ultraschallsensor+Multiplexer+Liniensensor

sky-Blau: Buzzer + Akkuüberwachung
Dark-Rote:Schrittmotor+Motortreiber

Relais

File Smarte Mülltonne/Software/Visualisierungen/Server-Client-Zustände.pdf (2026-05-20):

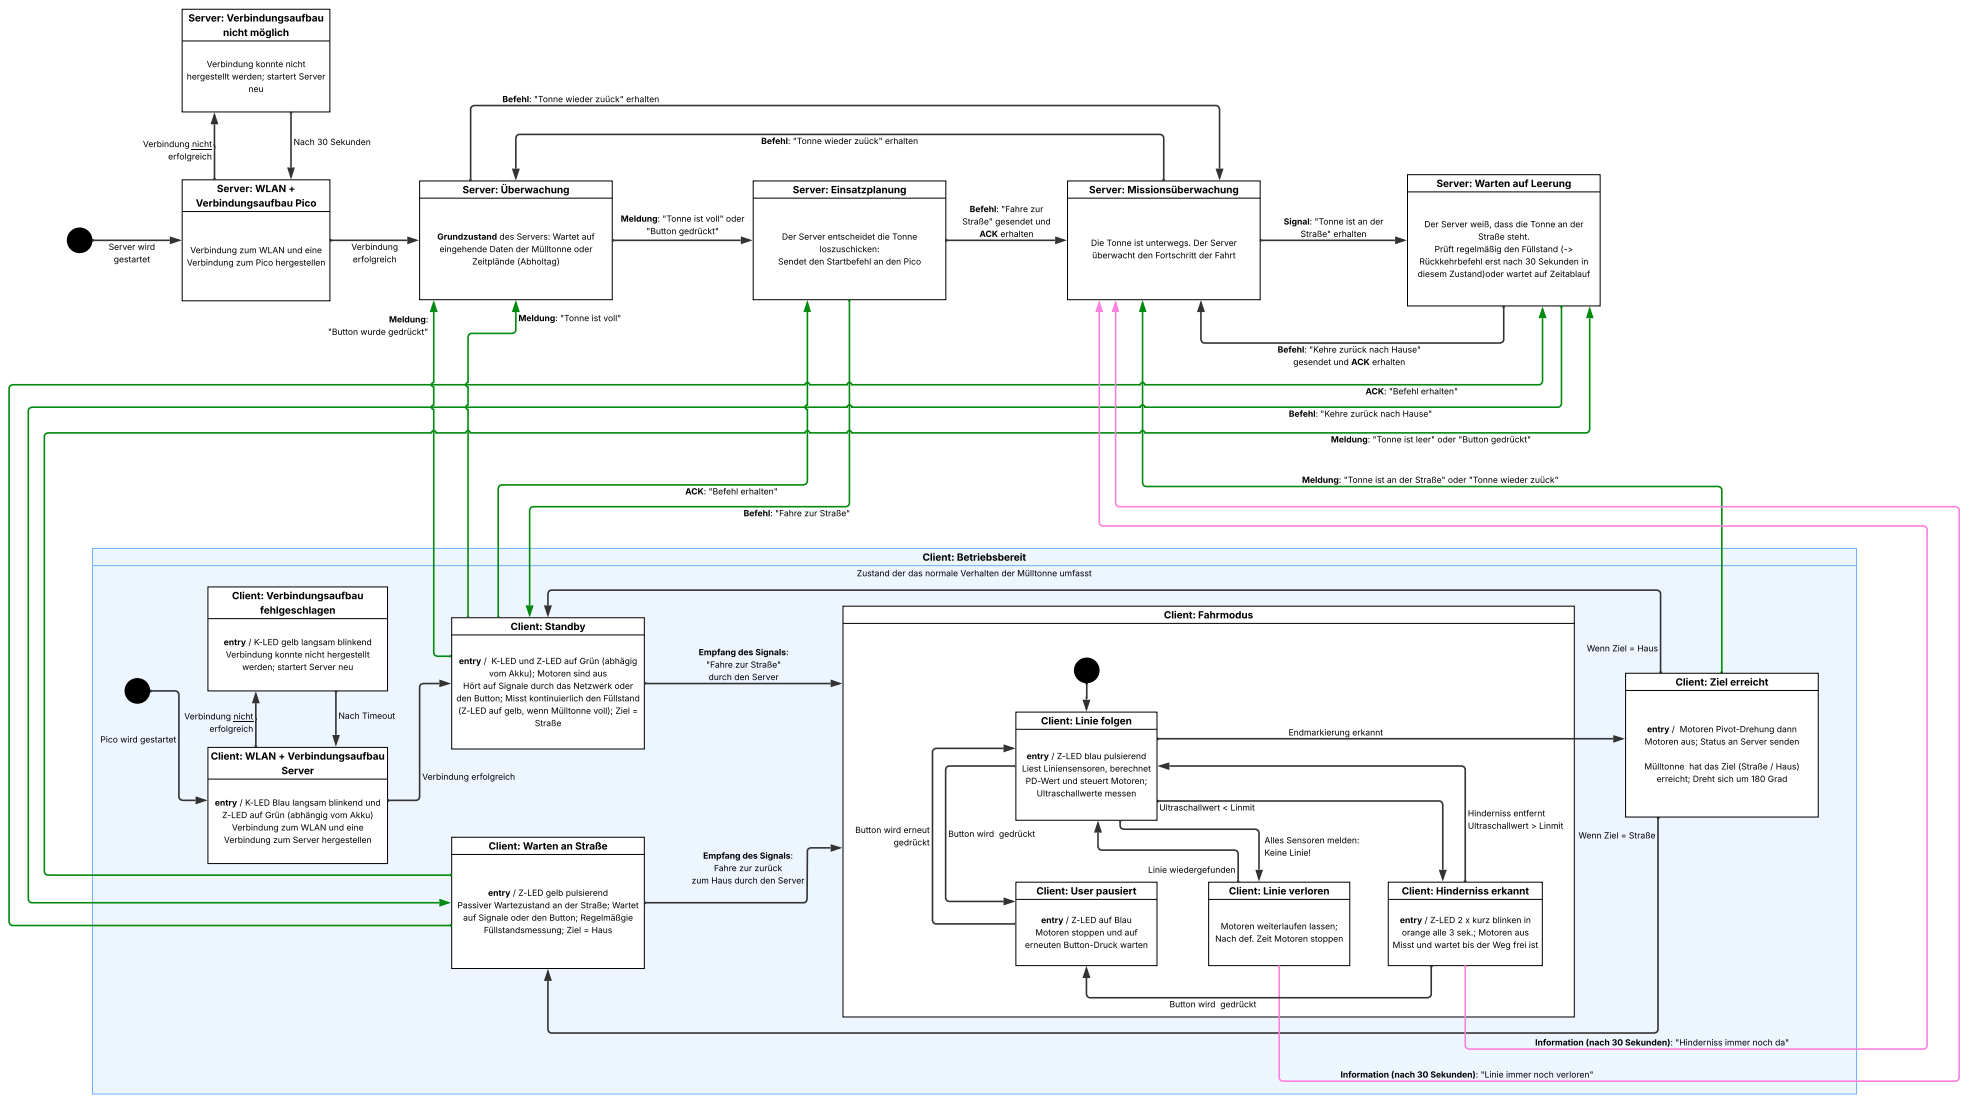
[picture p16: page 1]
Server: Überwachung; Zeitplände (Abholtag); Verbindung erfolgreich; Server wird gestartet; Server: Einsatzplanung; loszuschicken:; Server: Missionsüberwachung; Straße steht.; Client: Betriebsbereit; Füllstandsmessung; Ziel =; Haus; Client: Fahrmodus; gedrückt; Endmarkierung erkannt; Ultraschallwert < Linmit; Hinderniss entfernt; Ultraschallwert > Linmit; Wenn Ziel =; Linie wiedergefunden; Meldung: "Tonne ist voll" ldung:; Client: Standby; Straße; Client: Linie folgen; Liest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

Verbindung konnte nicht
hergestellt werden; startert Server

Befehl: "Tonne wieder zuück" erhalten

Server: Warten auf Leerung

Befehl: "Fahre zur
Straße" gesendet und
ACK erhalten

Meldung: "Tonne ist voll" oder
"Button gedrückt"

Signal: "Tonne ist an der
Straße" erhalten

Der Server weiß, dass die Tonne an der

Grundzustand des Servers: Wartet auf
eingehende Daten der Mülltonne oder

Der Server entscheidet die Tonne

Die Tonne ist unterwegs. Der Server
überwacht den Fortschritt der Fahrt

Verbindung zum WLAN und eine
Verbindung zum Pico hergestellen

Prüft regelmäßig den Füllstand (->
Rückkehrbefehl erst nach 30 Sekunden in
diesem Zustand)oder wartet auf Zeitablauf

Sendet den Startbefehl an den Pico

"Button wurde gedrückt"

Befehl: "Kehre zurück nach Hause"
gesendet und ACK erhalten

ACK: "Befehl erhalten"

Meldung: "Tonne ist leer" oder "Button gedrückt"

Meldung: "Tonne ist an der Straße" oder "Tonne wieder zuück"

Befehl: "Fahre zur Straße"

Zustand der das normale Verhalten der Mülltonne umfasst

entry / K-LED gelb langsam blinkend
Verbindung konnte nicht hergestellt
werden; startert Server neu

Empfang des Signals:
"Fahre zur Straße"
durch den Server

entry / K-LED und Z-LED auf Grün (abhägig

vom Akku); Motoren sind aus
Hört auf Signale durch das Netzwerk oder
den Button; Misst kontinuierlich den Füllstand
(Z-LED auf gelb, wenn Mülltonne voll); Ziel =

Client: Ziel erreicht

entry / Motoren Pivot-Drehung dann
Motoren aus; Status an Server senden

Pico wird gestartet

Client: WLAN + Verbindungsaufbau

entry / Z-LED blau pulsierend
PD-Wert und steuert Motoren;
Ultraschallwerte messen

Mülltonne hat das Ziel (Straße / Haus)
erreicht; Dreht sich um 180 Grad

entry / K-LED Blau langsam blinkend und
Z-LED auf Grün (abhängig vom Akku)
Verbindung zum Server hergestellen

Button wird erneut

Button wird gedrückt

Wenn Ziel = Straße

Alles Sensoren melden:
Keine Linie!

Client: Warten an Straße

Fahre zur zurück
zum Haus durch den Server

entry / Z-LED gelb pulsierend

Client: User pausiert

Client: Linie verloren

Client: Hinderniss erkannt

Passiver Wartezustand an der Straße; Wartet
auf Signale oder den Button; Regelmäßgie

entry / Z-LED auf Blau
Motoren stoppen und auf
erneuten Button-Druck warten

entry / Z-LED 2 x kurz blinken in
orange alle 3 sek.; Motoren aus
Misst und wartet bis der Weg frei ist

Motoren weiterlaufen lassen;
Nach def. Zeit Motoren stoppen

Information (nach 30 Sekunden): "Hinderniss immer noch da"

Information (nach 30 Sekunden): "Linie immer noch verloren"

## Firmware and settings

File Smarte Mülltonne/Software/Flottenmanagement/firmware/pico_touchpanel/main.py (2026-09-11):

# =============================================================================
# >>> LIVE-FIRMWARE  ·  Smarte Mülltonne 2.0  ·  Pico (Touchpanel + Fahrlogik) <<<
#
# DAS IST DER PRODUKTIVE, ZULETZT GETESTETE STAND (Inline-Stack).
# GENAU DIESE DATEI WIRD AUF DEN PICO GEFLASHT.
#
# Pfad: Smarte Mülltonne/Software/Flottenmanagement/firmware/pico_touchpanel/main.py
#
# Enthält self-contained: Touchpanel-UI, Liniensensor-PD-Regelung, Motor-
# steuerung, echte Heimfahrt (run_to_home: 180° → zurück → 180°), Sofort-Stopp
# während der Fahrt und den TCP-Bridge-Client (Web-App-Steuerung, Tonne 22).
#
# NICHT verwechseln mit dem MODULAREN Stack unter Quellcode/Client/main.py –
# der läuft NICHT auf dem Pico. Vollständige Einordnung:
# Flottenmanagement/docs/handoff_fahrlogik_2026-06-27.md  (§1 „Welcher Code läuft wirklich")
# =============================================================================

from machine import Pin, PWM
from time import sleep_ms, sleep_us, ticks_diff, ticks_ms, ticks_us

from config import (
    BRIDGE_HOST,
    BRIDGE_PORT,
    ENABLE_TCP_BRIDGE,
    PIN_BACKLIGHT,
    TCP_STATUS_MS,
    WLAN_PASSWORD,
    WLAN_SSID,
)
from display import BLACK, BLUE, GREEN, ILI9341, ORANGE, RED, WHITE
from touch import XPT2046
from ui import SCREEN_STATUS, TouchUi


# ============================================================
# Touchpanel + PD-Schrittmotor-Regelung in einer main.py
#
# Start ueber Touchpanel:
# PIN -> Fahren -> Abholung
#
# Die Motorlogik ist absichtlich direkt in dieser Datei enthalten,
# damit kein zusaetzliches pd_motor_linien_touch.py importiert werden muss.
# ============================================================


display = None
touch = None
ui = None
motors = None
_backlight = None
bridge_client = None
pico_state = "STANDBY"

# Fahr-/Abbruch-Steuerung: erlaubt Stopp per Bridge MITTEN in einer Fahrt.
_driving = False
_abort_drive = False

CMD_GOTO_STREET = "CMD_GOTO_STREET"
CMD_RETURN_HOME = "CMD_RETURN_HOME"
CMD_STOP = "CMD_STOP"


# ---------------- TOUCHPANEL / ANZEIGE ----------------
def set_backlight(enabled):
    global _backlight
    if PIN_BACKLIGHT is None:
        return
    if _backlight is None:
        _backlight = Pin(PIN_BACKLIGHT, Pin.OUT, value=1)
    _backlight.value(1 if enabled else 0)


def show_status(location=None, status_kind=None, **kw):
    """Zeigt den echten Wireframe-Status-Screen (ersetzt die alten Text-Screens).

    location="home" -> Haus-Symbol oben, location="truck" -> Muellwagen-Symbol.
    status_kind="position" laesst draw_status auf das Positions-Vollbild fallen.
    """
    if ui is None:
        return
    if ui.screen != SCREEN_STATUS:
        ui.go(SCREEN_STATUS)
    ui.set_status(location=location, status_kind=status_kind, **kw)


def show_drive_result(result):
    if result == "street":
        # an der Abholposition angekommen -> Muellwagen-Symbol
        show_status(location="truck", status_kind="position")
    elif result == "obstacle":
        show_status(status_kind="obstacle")
    elif result == "line_lost":
        show_status(status_kind="line_lost", line_ok=False)
    else:
        # aborted / unbekannt -> zurueck auf den Positions-Screen
        show_status(status_kind="position")


def send_bridge_line(line):
    if bridge_client is None:
        return
    try:
        bridge_client.send_line(line)
    except Exception as exc:
        print("Bridge send failed:", exc)


def set_pico_state(state, notify=True):
    global pico_state
    pico_state = state
    if notify:
        send_bridge_line("STATUS:" + state)


def get_pico_state():
    return pico_state


def finish_drive_result(result):
    if result == "street":
        set_pico_state("WAIT_AT_STREET", notify=False)
        send_bridge_line("ARRIVED: STREET")
    elif result == "obstacle":
        set_pico_state("OBSTACLE")
    elif result == "line_lost":
        set_pico_state("LINE_LOST")
    elif result == "aborted":
        set_pico_state("USER_PAUSED")
    else:
        set_pico_state("USER_PAUSED")


def _drive_pump():
    # Waehrend einer (blockierenden) Fahrt die Bridge weiter bedienen:
    # eingehende Befehle lesen (z.B. Stopp) + Status senden.
    # Rueckgabe True, wenn die Fahrt abgebrochen werden soll.
    if bridge_client is not None:
        try:
            bridge_client.tick()
        except Exception as exc:
            print("bridge tick failed:", exc)
    return _abort_drive


def start_goto_street(source):
    global _driving, _abort_drive
    _abort_drive = False
    _driving = True
    try:
        _run_goto_street(source)
    finally:
        _driving = False


def _run_goto_street(source):
    if source == "bridge":
        send_bridge_line("ACK " + CMD_GOTO_STREET)
    else:
        send_bridge_line("STATUS:MANUAL_GOTO_STREET_REQUEST")

    set_pico_state("LINE_FOLLOWING")
    # Waehrend der Fahrt zur Abholpos: "Linie erkannt"-Screen mit Muellwagen-Symbol oben
    show_status(location="truck", status_kind="line_ok")
    result = follow_line(leave_pad_first=False)
    finish_drive_result(result)
    show_drive_result(result)


def start_return_home(source):
    global _driving, _abort_drive
    _abort_drive = False
    _driving = True
    try:
        _run_return_home(source)
    finally:
        _driving = False


def _run_return_home(source):
    if source == "bridge":
        send_bridge_line("ACK " + CMD_RETURN_HOME)
    else:
        send_bridge_line("STATUS:MANUAL_RETURN_HOME_REQUEST")

    set_pico_state("LINE_FOLLOWING")
    # Heimwaerts: Haus-Symbol oben + "Linie erkannt"
    show_status(location="home", status_kind="line_ok")
    result = run_to_home()

    if result == "home":
        send_bridge_line("ARRIVED: HOME")
        set_pico_state("STANDBY")
        show_status(location="home", status_kind="position")
    else:
        # obstacle / line_lost / aborted -> bestehende Ergebnis-Behandlung
        finish_drive_result(result)
        show_drive_result(result)


def handle_bridge_command(cmd):
    global _abort_drive
    print("Bridge command:", cmd)

    if _driving:
        # Mitten in einer Fahrt: nur Stopp wird sofort beachtet -> Abbruch.
        if cmd == CMD_STOP:
            send_bridge_line("ACK " + CMD_STOP)
            _abort_drive = True
            if motors is not None:
                motors.stop()
        else:
            print("Befehl waehrend Fahrt ignoriert:", cmd)
        return

    if cmd == CMD_GOTO_STREET:
        start_goto_street("bridge")
        return

    if cmd == CMD_RETURN_HOME:
        start_return_home("bridge")
        return

    if cmd == CMD_STOP:
        send_bridge_line("ACK " + CMD_STOP)
        if motors is not None:
            motors.stop()
        set_pico_state("USER_PAUSED")
        # aktuellen Positions-Screen zeigen (kein Text-Screen)
        show_status()
        return

    print("Unknown bridge command:", cmd)


def create_bridge_client():
    if not ENABLE_TCP_BRIDGE:
        return None
    try:
        from tcp_bridge_client import TcpBridgeClient
    except Exception as exc:
        print("TCP bridge client import failed:", exc)
        return None

    return TcpBridgeClient(
        WLAN_SSID,
        WLAN_PASSWORD,
        BRIDGE_HOST,
        BRIDGE_PORT,
        handle_bridge_command,
        status_provider=get_pico_state,
        status_interval_ms=TCP_STATUS_MS,
    )


# ---------------- MULTIPLEXER CD74HC4067 ----------------
MUX_S0_PIN = 2
MUX_S1_PIN = 3
MUX_S2_PIN = 4
MUX_S3_PIN = 5
MUX_SIGNAL_PIN = 28

s0 = Pin(MUX_S0_PIN, Pin.OUT)
s1 = Pin(MUX_S1_PIN, Pin.OUT)
s2 = Pin(MUX_S2_PIN, Pin.OUT)
s3 = Pin(MUX_S3_PIN, Pin.OUT)
mux_signal = Pin(MUX_SIGNAL_PIN, Pin.IN)

US_TRIGGER_PIN = 6
US_FRONT_CHANNEL = 5
US_STOP_CM = 15
US_INTERVAL_MS = 120
US_TIMEOUT_US = 30000

# Füllstandsanzeige über den vorderen Ultraschallsensor (portiert aus dem
# modularen FuellstandSensor): leerer Abstand -> 0 %, voller Abstand -> 100 %.
FUELLSTAND_LEER_CM = 40.0
FUELLSTAND_VOLL_CM = 5.0
FILL_MEASURE_INTERVAL_MS = 2000

us_trigger = Pin(US_TRIGGER_PIN, Pin.OUT)
us_trigger.value(0)

LINE_CHANNELS = [0, 1, 2, 3, 4]
LINE_WEIGHTS = [2, 1, 0, -1, -2]
LINE_DETECTED_VALUE = 1


# ---------------- MOTOREN ----------------
LEFT_DIR_PIN = 10
LEFT_STEP_PIN = 11
LEFT_ENABLE_PIN = 12

RIGHT_DIR_PIN = 13
RIGHT_STEP_PIN = 8
RIGHT_ENABLE_PIN = 9

ENABLE_ACTIVE_VALUE = 1
LEFT_FORWARD_DIR = 1
RIGHT_FORWARD_DIR = 0

MIN_FREQ = 2000
MAX_FREQ = 4500
LEFT_TRIM_FACTOR = 1.0
RIGHT_TRIM_FACTOR = 1.0

BASE_SPEED = 45
MIN_SPEED = 0
MAX_SPEED = 95

KP = 32
KD = 2
MAX_CORRECTION = 80
MAX_DERIVATIVE_PER_S = 45

CONTROL_INTERVAL_MS = 25
PRINT_INTERVAL_MS = 250
LOST_LINE_STOP_MS = 10000

# 180-Grad-Drehung auf der Stelle (aus dem Handtest kalibriert).
TURN_SPEED = 35
TURN_180_STEPS = 43000
# Kurze Pause (Motoren aus) vor jeder 180-Grad-Drehung, damit sichtbar ist,
# dass das 5-Sensor-End-Pad erkannt wurde.
PIVOT_PAUSE_MS = 1000


def clamp(value, low, high):
    if value < low:
        return low
    if value > high:
        return high
    return value


class PDController:
    def __init__(self, kp, kd, max_correction, max_derivative_per_s):
        self.kp = kp
        self.kd = kd
        self.max_correction = max_correction
        self.max_derivative_per_s = max_derivative_per_s
        self.last_error = 0
        self.last_ms = None

    def calculate(self, current_position, target_position=0, now_ms=None):
        if current_position is None:
            self.reset()
            return 0

        if now_ms is None:
            now_ms = ticks_ms()

        error = current_position - target_position

        if self.last_ms is None:
            dt_s = CONTROL_INTERVAL_MS / 1000.0
        else:
            dt_s = max(0.001, ticks_diff(now_ms, self.last_ms) / 1000.0)

        derivative_per_s = (error - self.last_error) / dt_s
        derivative_per_s = clamp(
            derivative_per_s,
            -self.max_derivative_per_s,
            self.max_derivative_per_s,
        )

        self.last_error = error
        self.last_ms = now_ms

        correction = error * self.kp + derivative_per_s * self.kd
        return clamp(correction, -self.max_correction, self.max_correction)

    def reset(self):
        self.last_error = 0
        self.last_ms = None


class DualStepperMotorPWM:
    def __init__(
        self,
        left_dir_pin,
        left_step_pin,
        left_enable_pin,
        right_dir_pin,
        right_step_pin,
        right_enable_pin,
        min_freq=2000,
        max_freq=4500,
        left_trim_factor=1.0,
        right_trim_factor=1.0,
        enable_active_value=1,
        name="DUAL_STEPPER",
        debug=False,
    ):
        self.left_dir = Pin(left_dir_pin, Pin.OUT)
        self.right_dir = Pin(right_dir_pin, Pin.OUT)
        self.left_step = PWM(Pin(left_step_pin))
        self.right_step = PWM(Pin(right_step_pin))
        self.left_enable = Pin(left_enable_pin, Pin.OUT)
        self.right_enable = Pin(right_enable_pin, Pin.OUT)
        self.min_freq = min_freq
        self.max_freq = max_freq
        self.left_trim_factor = left_trim_factor
        self.right_trim_factor = right_trim_factor
        self.enable_active_value = enable_active_value
        self.disable_value = 0 if enable_active_value == 1 else 1
        self.name = name
        self.debug = debug
        self.last_left_speed = None
        self.last_right_speed = None
        self.stop()

    def enable(self):
        self.left_enable.value(self.enable_active_value)
        self.right_enable.value(self.enable_active_value)

    def disable(self):
        self.left_enable.value(self.disable_value)
        self.right_enable.value(self.disable_value)

    def stop(self):
        self.left_step.duty_u16(0)
        self.right_step.duty_u16(0)
        self.disable()
        self.last_left_speed = 0
        self.last_right_speed = 0
        if self.debug:
            print(self.name, "STOP")

    def _speed_to_frequency(self, speed, trim_factor):
        speed = clamp(speed, 0, 100)
        adjusted_speed = clamp(speed * trim_factor, 0, 100)
        if adjusted_speed <= 0:
            return 0
        return int(
            self.min_freq
            + (self.max_freq - self.min_freq) * (adjusted_speed / 100)
        )

    def drive_forward_differential(self, left_speed, right_speed):
        left_speed = clamp(left_speed, 0, 100)
        right_speed = clamp(right_speed, 0, 100)

        if left_speed <= 0 and right_speed <= 0:
            self.stop()
            return

        left_freq = self._speed_to_frequency(left_speed, self.left_trim_factor)
        right_freq = self._speed_to_frequency(right_speed, self.right_trim_factor)

        self.enable()
        self.left_dir.value(LEFT_FORWARD_DIR)
        self.right_dir.value(RIGHT_FORWARD_DIR)
        sleep_ms(2)

        if left_freq > 0:
            self.left_step.freq(left_freq)
            self.left_step.duty_u16(32768)
        else:
            self.left_step.duty_u16(0)

        if right_freq > 0:
            self.right_step.freq(right_freq)
            self.right_step.duty_u16(32768)
        else:
            self.right_step.duty_u16(0)

        self.last_left_speed = left_speed
        self.last_right_speed = right_speed

        if self.debug:
            print(
                self.name,
                "L",
                round(left_speed, 1),
                left_freq,
                "R",
                round(right_speed, 1),
                right_freq,
            )

    def turn_in_place(self, speed, clockwise=True):
        # Drehung auf der Stelle: eine Kette vorwaerts, die andere rueckwaerts.
        speed = clamp(speed, 0, 100)
        if speed <= 0:
            self.stop()
            return

        left_freq = self._speed_to_frequency(speed, self.left_trim_factor)
        right_freq = self._speed_to_frequency(speed, self.right_trim_factor)

        self.enable()
        if clockwise:
            # Rechtsdrehung: linke Kette vorwaerts, rechte rueckwaerts
            self.left_dir.value(LEFT_FORWARD_DIR)
            self.right_dir.value(1 - RIGHT_FORWARD_DIR)
        else:
            self.left_dir.value(1 - LEFT_FORWARD_DIR)
            self.right_dir.value(RIGHT_FORWARD_DIR)
        sleep_ms(2)

        if left_freq > 0:
            self.left_step.freq(left_freq)
            self.left_step.duty_u16(32768)
        if right_freq > 0:
            self.right_step.freq(right_freq)
            self.right_step.duty_u16(32768)

        self.last_left_speed = speed
        self.last_right_speed = speed

    def steps_to_ms(self, steps, speed):
        freq = self._speed_to_frequency(speed, 1.0)
        if freq <= 0:
            return 0
        return int((steps * 1000) / freq)


def create_motors(debug=False):
    return DualStepperMotorPWM(
        left_dir_pin=LEFT_DIR_PIN,
        left_step_pin=LEFT_STEP_PIN,
        left_enable_pin=LEFT_ENABLE_PIN,
        right_dir_pin=RIGHT_DIR_PIN,
        right_step_pin=RIGHT_STEP_PIN,
        right_enable_pin=RIGHT_ENABLE_PIN,
        min_freq=MIN_FREQ,
        max_freq=MAX_FREQ,
        left_trim_factor=LEFT_TRIM_FACTOR,
        right_trim_factor=RIGHT_TRIM_FACTOR,
        enable_active_value=ENABLE_ACTIVE_VALUE,
        name="Muelltonne",
        debug=debug,
    )


def select_channel(channel):
    s0.value(channel & 1)
    s1.value((channel >> 1) & 1)
    s2.value((channel >> 2) & 1)
    s3.value((channel >> 3) & 1)
    sleep_us(500)


def read_line_sensor(channel):
    select_channel(channel)
    sleep_us(300)
    return mux_signal.value()


def read_line_sensors():
    values = []
    for channel in LINE_CHANNELS:
        values.append(read_line_sensor(channel))
    return values


def measure_ultrasonic(channel):
    select_channel(channel)

    us_trigger.value(0)
    sleep_us(2)
    us_trigger.value(1)
    sleep_us(10)
    us_trigger.value(0)

    start_timeout = ticks_us()
    while mux_signal.value() == 0:
        if ticks_diff(ticks_us(), start_timeout) > US_TIMEOUT_US:
            return None

    start = ticks_us()
    while mux_signal.value() == 1:
        if ticks_diff(ticks_us(), start) > US_TIMEOUT_US:
            return None

    end = ticks_us()
    duration = ticks_diff(end, start)
    return duration / 58.0


def obstacle_detected(distance_cm):
    return distance_cm is not None and distance_cm <= US_STOP_CM


def measure_fill_percent():
    # Füllstand aus dem vorderen Ultraschallsensor: leer -> 0 %, voll -> 100 %.
    # Rueckgabe None bei fehlendem Echo (z.B. Deckel offen / kein Reflex).
    distance = measure_ultrasonic(US_FRONT_CHANNEL)
    if distance is None:
        return None
    if distance >= FUELLSTAND_LEER_CM:
        return 0
    if distance <= FUELLSTAND_VOLL_CM:
        return 100
    span = FUELLSTAND_LEER_CM - FUELLSTAND_VOLL_CM
    ratio = (FUELLSTAND_LEER_CM - distance) / span
    if ratio < 0.0:
        ratio = 0.0
    if ratio > 1.0:
        ratio = 1.0
    return int(round(ratio * 100))


def calculate_line_position(values):
    if all(value == LINE_DETECTED_VALUE for value in values):
        return "street"

    weighted_sum = 0
    active_count = 0

    for index, value in enumerate(values):
        if value == LINE_DETECTED_VALUE:
            weighted_sum += LINE_WEIGHTS[index]
            active_count += 1

    if active_count == 0:
        return None

    return weighted_sum / active_count


def speeds_from_correction(correction):
    left_speed = BASE_SPEED - correction
    right_speed = BASE_SPEED + correction
    left_speed = clamp(left_speed, MIN_SPEED, MAX_SPEED)
    right_speed = clamp(right_speed, MIN_SPEED, MAX_SPEED)
    return left_speed, right_speed


def follow_line(leave_pad_first=False):
    global motors

    if motors is None:
        motors = create_motors(debug=False)

    controller = PDController(KP, KD, MAX_CORRECTION, MAX_DERIVATIVE_PER_S)
    last_control_ms = ticks_ms()
    last_print_ms = ticks_ms()
    last_us_ms = ticks_ms()
    last_line_seen_ms = ticks_ms()
    last_left_speed = BASE_SPEED
    last_right_speed = BASE_SPEED
    front_distance_cm = None

    # Leave-Pad-Guard: Das End-T-Pad zaehlt erst als Ziel, nachdem das
    # Start-Pad einmal verlassen wurde (Linie gesehen). Wichtig fuer die
    # Rueckfahrt, weil die Tonne nach der 180-Grad-Drehung noch auf dem Pad steht.
    armed = not leave_pad_first

    line_values = [0, 0, 0, 0, 0]
    position = None
    correction = 0
    left_speed = 0
    right_speed = 0

    print("Starte Linienfolger (leave_pad_first=" + str(leave_pad_first) + ")")

    try:
        while True:
            now_ms = ticks_ms()

            if ticks_diff(now_ms, last_us_ms) >= US_INTERVAL_MS:
                last_us_ms = now_ms
                front_distance_cm = measure_ultrasonic(US_FRONT_CHANNEL)

            if ticks_diff(now_ms, last_control_ms) >= CONTROL_INTERVAL_MS:
                last_control_ms = now_ms

                # Bridge bedienen (Stopp mitten in der Fahrt moeglich)
                if _drive_pump():
                    motors.stop()
                    print("Fahrt per Stopp abgebrochen")
                    return "aborted"

                line_values = read_line_sensors()
                position = calculate_line_position(line_values)

                if obstacle_detected(front_distance_cm):
                    motors.stop()
                    print("Stopp: Hindernis", front_distance_cm, "cm")
                    return "obstacle"

                if position == "street":
                    if armed:
                        motors.stop()
                        print("Stopp: T-Pad erkannt")
                        return "street"
                    # Noch auf dem Start-Pad -> geradeaus, bis verlassen
                    last_line_seen_ms = now_ms
                    correction = 0
                    left_speed = BASE_SPEED
                    right_speed = BASE_SPEED
                    last_left_speed = left_speed
                    last_right_speed = right_speed
                    motors.drive_forward_differential(BASE_SPEED, BASE_SPEED)
                elif position is not None:
                    armed = True
                    last_line_seen_ms = now_ms
                    correction = controller.calculate(position, 0, now_ms)
                    left_speed, right_speed = speeds_from_correction(correction)
                    last_left_speed = left_speed
                    last_right_speed = right_speed
                    motors.drive_forward_differential(left_speed, right_speed)
                else:
                    controller.reset()
                    correction = 0
                    if ticks_diff(now_ms, last_line_seen_ms) < LOST_LINE_STOP_MS:
                        left_speed = last_left_speed
                        right_speed = last_right_speed
                        motors.drive_forward_differential(left_speed, right_speed)
                    else:
                        motors.stop()
                        print("Stopp: Linie verloren")
                        return "line_lost"

                if ticks_diff(now_ms, last_print_ms) >= PRINT_INTERVAL_MS:
                    last_print_ms = now_ms
                    print(
                        "Sensoren:",
                        line_values,
                        "Position:",
                        position,
                        "Korrektur:",
                        round(correction, 1),
                        "Speed L/R:",
                        round(left_speed, 1),
                        round(right_speed, 1),
                        "armed:",
                        armed,
                        "US vorne:",
                        front_distance_cm,
                    )

    except KeyboardInterrupt:
        return "aborted"
    finally:
        motors.stop()
        print("Linienfolger gestoppt")
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

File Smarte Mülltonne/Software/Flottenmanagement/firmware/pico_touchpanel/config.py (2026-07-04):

from machine import Pin


# Display wiring from the working ILI9341 test.
SPI_ID = 0
SPI_BAUDRATE = 20_000_000
PIN_SCK = 18
PIN_MOSI = 19
PIN_MISO = 16
PIN_DISPLAY_CS = 17
PIN_DISPLAY_DC = 20
PIN_DISPLAY_RST = 21

# XPT2046 touch wiring. Adjust T_CS/T_IRQ after checking the real module.
# Keep CS separate from MISO; 22 is a safe placeholder, not a confirmed wire.
PIN_TOUCH_CS = 22
PIN_TOUCH_IRQ = None

# XPT2046 calibration from the on-device 5-point calibration.
# The panel reports swapped axes in landscape rotation 0x28.
TOUCH_X_MIN = 374
TOUCH_X_MAX = 3895
TOUCH_Y_MIN = 273
TOUCH_Y_MAX = 3857
TOUCH_SWAP_XY = True
TOUCH_INVERT_X = True
TOUCH_INVERT_Y = True

# Display backlight pin (GPIO 15), per PWM dimmbar (Eco-Modus).
PIN_BACKLIGHT = 15

# Landscape UI target.
WIDTH = 320
HEIGHT = 240

# ILI9341 MADCTL rotation value. If the UI is mirrored/rotated on hardware,
# try 0x28, 0x88 or 0xE8 and keep WIDTH/HEIGHT at 320x240.
DISPLAY_ROTATION = 0x28

# Backend settings for later integration.
BIN_ID = 1
BACKEND_URL = "http://192.168.0.10:8000"
POLL_COMMAND_MS = 2000
POST_STATUS_MS = 8000
ENABLE_BACKEND_ACTIONS = False
ADMIN_TOKEN = ""

# TCP bridge demo path for the current SmartBinDemo test network.
ENABLE_TCP_BRIDGE = True
WLAN_SSID = "SmartBinDemo"
WLAN_PASSWORD = "SmartBin2026!"
BRIDGE_HOST = "192.168.50.10"
BRIDGE_PORT = 50002
TCP_STATUS_MS = 2000

# Local maintenance PIN. The on-screen keypad supports digits plus * and #.
MAINTENANCE_PIN = "12#"


def make_output(pin_no, value=1):
    pin = Pin(pin_no, Pin.OUT)
    pin.value(value)
    return pin

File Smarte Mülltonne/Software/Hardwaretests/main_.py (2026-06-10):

from machine import Pin
from time import sleep, sleep_ms, sleep_us, ticks_diff, ticks_us


# Diese Datei heisst main.py, damit sie auf dem Pico beim Einschalten
# automatisch gestartet wird.


# ---------------- EINSTELLUNGEN ----------------
DEBUG = False
STARTUP_DELAY_S = 2

FORWARD = 1
BACKWARD = 0
LINE_DETECTED = 1
US_LIMIT_CM = 30

MOTOR1_STEPS = 40000
MOTOR2_STEPS = 40000
STEP_DELAY_US = 2


# ---------------- MULTIPLEXER CD74HC4067 ----------------
# S0-S3 steuern den ausgewaehlten Kanal C0-C15.
s0 = Pin(2, Pin.OUT)
s1 = Pin(3, Pin.OUT)
s2 = Pin(4, Pin.OUT)
s3 = Pin(5, Pin.OUT)

# Gemeinsamer Trigger fuer alle Ultraschallsensoren
trigger = Pin(6, Pin.OUT)

# SIG/Z/COM vom Multiplexer am Pico
mux_signal = Pin(28, Pin.IN)

# C0-C4: Liniensensoren 1-5
# C5-C8: Ultraschallsensoren 1-4
LINE_CHANNELS = [0, 1, 2, 3, 4]
US_CHANNELS = [5, 6, 7, 8]


# ---------------- MOTOREN ----------------
MOTOR1_DIR_PIN = 10
MOTOR1_STEP_PIN = 11
MOTOR1_ENABLE_PIN = 12

MOTOR2_DIR_PIN = 13
MOTOR2_STEP_PIN = 14
MOTOR2_ENABLE_PIN = 15


def log(*values):
    if DEBUG:
        print(*values)


def create_status_led():
    try:
        return Pin("LED", Pin.OUT)
    except Exception:
        return Pin(25, Pin.OUT)


status_led = create_status_led()


class Stepper:
    def __init__(self, dir_pin, step_pin, enable_pin, delay_us=2000, name="STEPPER"):
        self.dir = Pin(dir_pin, Pin.OUT)
        self.step = Pin(step_pin, Pin.OUT)
        self.enable = Pin(enable_pin, Pin.OUT)
        self.delay_us = delay_us
        self.name = name

        self.step.value(0)
        self.stop()

    def enable_motor(self):
        self.enable.value(1)

    def stop(self):
        self.step.value(0)
        self.enable.value(0)

    def set_direction(self, direction):
        self.dir.value(direction)

    def step_once(self):
        self.step.value(1)
        sleep_us(self.delay_us)
        self.step.value(0)
        sleep_us(self.delay_us)

    def move(self, steps, direction):
        self.enable_motor()
        self.set_direction(direction)

        log(self.name, "dir:", direction, "steps:", steps)

        for _ in range(steps):
            self.step_once()

        self.stop()


class Robot:
    def __init__(self, motor1, motor2):
        self.m1 = motor1
        self.m2 = motor2

    def stop(self):
        self.m1.stop()
        self.m2.stop()

    def motor1_forward(self):
        log("Motor 1 vorwaerts, Motor 2 stop")
        self.m2.stop()
        self.m1.move(MOTOR1_STEPS, FORWARD)

    def motor2_forward(self):
        log("Motor 2 vorwaerts, Motor 1 stop")
        self.m1.stop()
        self.m2.move(MOTOR2_STEPS, FORWARD)

    def both_forward(self):
        log("Motor 1 + Motor 2 vorwaerts")
        self.move_both(MOTOR1_STEPS, MOTOR2_STEPS, FORWARD, FORWARD)

    def both_backward(self):
        log("Motor 1 + Motor 2 rueckwaerts")
        self.move_both(MOTOR1_STEPS, MOTOR2_STEPS, BACKWARD, BACKWARD)

    def motor1_backward(self):
        log("Motor 1 rueckwaerts, Motor 2 stop")
        self.m2.stop()
        self.m1.move(MOTOR1_STEPS, BACKWARD)

    def motor2_backward(self):
        log("Motor 2 rueckwaerts, Motor 1 stop")
        self.m1.stop()
        self.m2.move(MOTOR2_STEPS, BACKWARD)

    def move_both(self, steps1, steps2, direction1, direction2):
        self.m1.enable_motor()
        self.m2.enable_motor()
        self.m1.set_direction(direction1)
        self.m2.set_direction(direction2)

        max_steps = max(steps1, steps2)
        accumulator1 = 0
        accumulator2 = 0

        for _ in range(max_steps):
            accumulator1 += steps1
            accumulator2 += steps2

            do_step1 = accumulator1 >= max_steps
            do_step2 = accumulator2 >= max_steps

            if do_step1:
                self.m1.step.value(1)
                accumulator1 -= max_steps
            if do_step2:
                self.m2.step.value(1)
                accumulator2 -= max_steps

            sleep_us(STEP_DELAY_US)

            if do_step1:
                self.m1.step.value(0)
            if do_step2:
                self.m2.step.value(0)

            sleep_us(STEP_DELAY_US)

        self.stop()


def select_channel(channel):
    s0.value(channel & 1)
    s1.value((channel >> 1) & 1)
    s2.value((channel >> 2) & 1)
    s3.value((channel >> 3) & 1)
    sleep_ms(10)


def read_line_sensor(channel):
    select_channel(channel)
    sleep_ms(2)
    return mux_signal.value()


def measure_ultrasonic(channel):
    select_channel(channel)

    trigger.value(0)
    sleep_us(2)
    trigger.value(1)
    sleep_us(10)
    trigger.value(0)

    start_timeout = ticks_us()
    while mux_signal.value() == 0:
        if ticks_diff(ticks_us(), start_timeout) > 30000:
            return None

    start = ticks_us()
    while mux_signal.value() == 1:
        if ticks_diff(ticks_us(), start) > 30000:
            return None

    end = ticks_us()
    duration = ticks_diff(end, start)
    return duration / 58.0


def read_line_sensors():
    values = []

    for channel in LINE_CHANNELS:
        values.append(read_line_sensor(channel))

    return values


def read_ultrasonic_sensors():
    distances = []

    for channel in US_CHANNELS:
        distances.append(measure_ultrasonic(channel))
        sleep_ms(80)

    return distances


def is_too_close(distance):
    return distance is not None and distance < US_LIMIT_CM


def startup_signal():
    for _ in range(3):
        status_led.value(1)
        sleep_ms(150)
        status_led.value(0)
        sleep_ms(150)


def heartbeat():
    status_led.value(1)
    sleep_ms(20)
    status_led.value(0)
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

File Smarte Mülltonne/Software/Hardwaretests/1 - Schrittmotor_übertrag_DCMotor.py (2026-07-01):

from machine import Pin, PWM
from time import sleep


class DualStepperMotorPWM:
    """
    Treiberklasse für zwei Schrittmotoren mit STEP/DIR/ENABLE-Treibern.

    Geschwindigkeit wird über die STEP-Frequenz gesteuert.
    Beide Motoren werden zeitgleich per PWM angesteuert.
    """

    def __init__(self,
                 left_dir_pin,
                 left_step_pin,
                 left_enable_pin,
                 right_dir_pin,
                 right_step_pin,
                 right_enable_pin,
                 min_freq=2000,
                 max_freq=4500,
                 left_trim_factor=1.0,
                 right_trim_factor=1.0,
                 enable_active_value=1,
                 name="DUAL_STEPPER",
                 debug=True):

        self.left_dir = Pin(left_dir_pin, Pin.OUT)
        self.right_dir = Pin(right_dir_pin, Pin.OUT)

        self.left_step = PWM(Pin(left_step_pin))
        self.right_step = PWM(Pin(right_step_pin))

        self.left_enable = Pin(left_enable_pin, Pin.OUT)
        self.right_enable = Pin(right_enable_pin, Pin.OUT)

        self.min_freq = min_freq
        self.max_freq = max_freq

        self.left_trim_factor = left_trim_factor
        self.right_trim_factor = right_trim_factor

        self.enable_active_value = enable_active_value
        self.disable_value = 0 if enable_active_value == 1 else 1

        self.name = name
        self.debug = debug

        self.current_mode = "stop"
        self.current_speed = 0

        self.stop()

    def enable(self):
        self.left_enable.value(self.enable_active_value)
        self.right_enable.value(self.enable_active_value)

    def disable(self):
        self.left_enable.value(self.disable_value)
        self.right_enable.value(self.disable_value)

    def stop(self):
        self.left_step.duty_u16(0)
        self.right_step.duty_u16(0)
        self.disable()

        self.current_mode = "stop"
        self.current_speed = 0

        if self.debug:
            print(self.name, "STOP")

    def _speed_to_frequency(self, speed, trim_factor):
        speed = max(0, min(100, int(speed)))
        adjusted_speed = int(speed * trim_factor)
        adjusted_speed = max(0, min(100, adjusted_speed))

        if adjusted_speed == 0:
            return 0

        return int(
            self.min_freq +
            (self.max_freq - self.min_freq) * (adjusted_speed / 100)
        )

    def _drive(self, mode, speed, left_dir, right_dir):
        speed = max(0, min(100, int(speed)))

        left_trim = self.left_trim_factor
        right_trim = self.right_trim_factor

        left_freq = self._speed_to_frequency(speed, left_trim)
        right_freq = self._speed_to_frequency(speed, right_trim)

        if left_freq <= 0 or right_freq <= 0:
            self.stop()
            return

        self.enable()

        self.left_dir.value(left_dir)
        self.right_dir.value(right_dir)
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

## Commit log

2026-05-20 Alle alten Inhalte
    sämtliche alten Inhalte (Code, Dokumentation, Diagramme, Rechnungen, Videos etc.)
    [Abdeckung.stl, Anzeige.stl-neu.stl, Deckel Anzeige neu.stl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]
2026-05-31 Update global_controller.py
    Überarbeitungen - Logik für Umfahrung bis zu dem Punkt des wirklichen Fahrens eingebaut
2026-06-11 Touchpanel überarbeitet, WebApp Deployment vorgenommen
    Achtung! Touchpanel hat Bugs -werden noch behoben.
    [config.py, display.py, main.py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]
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2026-06-12 Anpassungen Touchpanel & WebApp
    Dark Mode in Web App, Müllwagen route überarbeitet (Fliegt noch zurück - aber wird besser..)
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2026-06-21 Routenplanung: kapazitätsbasiert, auswählbar + dynamischer Verlauf
    - Kapazitätsgrenze: nur so viele Tonnen wie bis zur vollen Beladung passen (Depot->Tonnen->Depot); gemeinsame Kapazitaet/Schwelle in config (Planung + Simulator).
    - Mehrere Vorschlaege (Sweep/Optimiert/Volle zuerst) zur Auswahl im Google-Maps-Stil: grau -> Klick -> gelb -> wird gefahren; Default autonom.
    - Dynamischer Routenverlauf: gefahren (grau) vs. kommend (gelb), naechster Abschnitt bis zur Abholposition hervorgehoben.
    - Auslastungs-Panel + Route-Modell/Migration: load_units, capacity_units, active, is_default, variant_label, plan_group; /routes/candidates + /activate.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
2026-06-22 Routen: Auto-Replan nach Depot-Entleerung + Render-Fix
    - Mehr-Trip-Kette: nach Abschluss + Entleerung am Depot wird automatisch die naechste kapazitaetsbegrenzte Fahrt fuer die restlichen vollen Tonnen geplant, bis keine mehr uebrig sind (Simulator-Auto-Replan via generate_route_candidates).
    - Abgeschlossene Route wird active=False; Routenplanung in wiederverwendbare generate_route_candidates() ausgelagert.
    - Render-Fix: Routenlinie folgt der Truck-Phase statt mehrdeutiger Projektion (Depot liegt an Anfang+Ende). Sammeln=gefahren/kommend, Rueckfahrt=gedaempft (kein gelbes Zurueckzeichnen), sonst Vorschau. Route+Kandidaten-Polling auf 3s.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
2026-06-22 Routen-Render: keine gestrichelten Linien entlang der gefahrenen Strecke
    - Kandidaten-Alternativen nur in der Vorschau-Phase zeigen (nicht waehrend der Fahrt), damit keine gestrichelten Linien ueber der befahrenen Route liegen / von gestrichelt zu solide springen.
    - Tonnen-Bewegungsstummel (home->pickup) nur fuer noch volle Tonnen, damit keine gestrichelten Reste entlang der schon abgefahrenen Strecke bleiben.
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2026-06-23 Demo-Netzwerk und Pico-Bridge vorbereiten
    - manuelle Hardware-Kommandos im Dashboard ergänzt
    - TCP-Bridge um Pickup-/Home-Befehlsalias erweitert
    - optionalen Pico-TCP-Client in die Touchpanel-Firmware integriert
    - Pico-TCP-Simulator für lokale Bridge-/Backend-Tests ergänzt
    - Demo-Runbook für TP-Link/WISP, Backend, Bridge, Web-App und Pico erstellt
    - Netzwerkfluss für Mac, privates TP-Link-WLAN und Pico vorbereitet
    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
2026-06-26 Add standalone test for line following and obstacle avoidance
    Implement standalone test for line following and obstacle avoidance with detailed control logic and sensor integration.
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2026-06-27 Sammellogik: positionsbasiert sammeln, voll->Depot, exakter Fahrt-Fortschritt
    - Positionsbasiertes (opportunistisches) Sammeln mit Kapazitaets-Grenze: jede volle Tonne, an der der Wagen vorbeikommt, wird mitgenommen solange Platz ist (Route oder nicht) - kein Vorbeifahren mehr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
    - Voll -> direkter Weg zum Depot: sobald keine sammelbare Tonne mehr reinpasst, Route abbrechen und direkt zum Depot, statt restliche Seitenstrassen abzuklappern. Rest via Auto-Replan.
    - Backend meldet route_progress (0..1); Frontend teilt damit exakt in gefahren/kommend statt per Projektion -> kein gelbes Neuzeichnen hinter dem Wagen mehr. Ro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
2026-06-27 Chat-Agent: Schwerpunkt-Wahl + Listen-Fix der Routenplanung
    - plan_route/dispatch_truck verarbeiten jetzt die Kandidatenliste von /routes/plan (vorher Crash, da Einzel-Route erwartet).
    - Optionaler focus-Parameter: 'kurze strecke' | 'dringende' | 'viele tonnen' waehlt den passenden Kandidaten und aktiviert ihn. Prompt um die Schwerpunkte erweitert.
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2026-06-27 Pico Fahrlogik, Touchpanel
    Pico-Fahrlogik: echte Heimfahrt, Sofort-Stopp & Übergabe-Doku
    Finalisiert die autonome Fahrlogik im Inline-Stack (firmware/
    pico_touchpanel/main.py); voller Zyklus läuft in Tests wie gewollt.
    Heimfahrt:
    - Echte run_to_home(): 180°-Drehung an Abholpos -> Linie zurück
    folgen -> 180°-Drehung am Heim-T (vorher nur Stub mit gefaktem
    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
2026-06-28 Refine Pico state machine and avoidance logic
    - renamed line sensor end marker handling from street to end_marker
    - updated PD controller and global controller for end_marker
    - refined LINE_LOST behavior with stop, buzzer and display after timeout
    - updated OBSTACLE_WAIT to resume if front obstacle is removed
    - added TURN_AT_STREET and improved TURN_AT_HOME handling
    - introduced named avoid-step constants for AVOID_LEFT and AVOID_RIGHT
    - documented state machine changes and handover notes
    [180grad_returnzuLinie_und_angekommen_unterscheiden.py, PDcontroller.py]
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2026-07-01 Web-App-Sicherheits-Fixes + Aufraeumen
    - Auth-Gate (X-Admin-Token) fuer /admin/demo/reset und /truck/command
    - Truck-Command Action-Allow-List {start,pause,stop}
    - WebSocket-Socket-Leak (guarded disconnect + finally), truck-state gecacht
    - Frontend Reconnect-Leak (clearTimeout, isMounted-Guard, onerror)
    - Agent sendet Admin-Token; Admin-Page sendet Token beim Reset
    - veraltetes firmware/pico_touchpanel.zip entfernt
2026-07-01 Live-Firmware kennzeichnen (Pico-Produktivstand)
    Header in firmware/pico_touchpanel/main.py: markiert die Datei als den
    zuletzt getesteten, auf den Pico geflashten Inline-Stack (mit Bridge-Client
    + echter Heimfahrt), abgegrenzt vom modularen Quellcode/Client/main.py.
2026-07-01 Fuellstandsanzeige in Live-Firmware integriert
    measure_fill_percent() aus dem modularen FuellstandSensor portiert
    (vorderer Ultraschallsensor: leer 40cm -> 0%, voll 5cm -> 100%).
    Wird im Idle-Loop alle 2s gemessen und im Touchpanel-Status-Screen
    angezeigt (ui.set_status(fill_level=...)), nur bei Aenderung neu
    gezeichnet. Laeuft nur im Leerlauf, stoert die Fahrt/Hinderniserkennung
    nicht.
2026-07-01 Modularer Client-Stack: Bridge-Steuerung, Linienverfolgung + Umfahrung
    - TCP-Bridge/Web-App-Steuerung im modularen Controller (handle_network_command,
    get_network_status, set_network_client; sendet ACK CMD_*, STATUS, ARRIVED).
    tcp_bridge_client.py ergaenzt, WLAN/Bridge-Werte in config.py.
    - Linienverfolgung stabilisiert: Fahr-Status nur 1x/Fahrt (kein Display-Redraw
    im Regeltakt), Anlauframpe, LINE_LOST-Recovery. Parameter auf den bewaehrten
    Referenz-Satz (Test_2/1) gebracht: base_speed 60, max_freq 4500,
    max_correction 60, Kurven-Adaption neutralisiert.
    - Hindernisumfahrung robuster: Entlang-Phase entprellt (mehrere konsekutive
    Frei-Messungen), Sicherheits-Timeouts (avoid_side/l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
    [config.py, main.py, tcp_bridge_client.py]
2026-07-01 Client-Stack auf getesteten Stand (kp32/mc60) nach Merge
    Merge mit origin/main (TherPelz "Testanpassungen") hatte dessen PD-Werte
    (kp18/max_correction28) + force-Reads automatisch reingezogen. Wie im Team
    abgestimmt behalten wir unseren heute verifizierten Stand: main.py +
    global_controller_test.py exakt auf Commit 13c2992f zurueckgesetzt
    (kp32, max_correction60, base_speed60, max_freq4500 - fahren sauber, 0 Verluste).
2026-07-04 Spec: Touchpanel-Meldungen (Hygiene/Beschädigung) -> Web-App
    Design-Spec fuer den Vertical Slice: Panel-Buttons SCHADEN/HYGIENE loesen
    Meldungen aus, die ueber Bridge -> Backend (SecurityEvent) -> WebSocket live
    im Leitstand erscheinen und dort erledigt werden. Panel zeigt "Meldung gesendet".
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2026-07-04 Party-Modus (Easter-Egg): PIN '***' -> Tonne dreht sich + Buzzer-Jingle 10s
    - ui.py (firmware+Client): PIN '***' loest action 'party' aus
    - Controller: STATE_PARTY, request_party/_logic_party (turn_right speed 65, 10s,
    Buzzer-Pattern in Dauerschleife), nur aus AT_HOME; PARTY->STANDBY nach aussen
    [ui.py]
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2026-07-04 Pico: unbefugte Deckeloeffnung -> Buzzer-Alarm + REPORT:UNAUTHORIZED_OPEN
    - Querschnitt-Deckelcheck (~500ms): Fuellstand kein Echo = Deckel offen
    - scharf = ausser Haus UND nicht _disarm_by_truck (ARM/DISARM via Bridge)
    - offen & scharf -> sofort Buzzer-Alarm (laeuft bis zu/entschaerft) + einmalige Meldung
    - handle_network_command: ARM/DISARM
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2026-07-04 Spec: Hardware-Test Follow-up (2026-07-04)
    Sammel-Spec aus dem Hardware-Testlauf: Security-Quittieren pro Meldung,
    Zeitzonen-Fix (Backend UTC-aware), Diagnose-Zurück-Button, Diagnose-Live-Werte,
    Touch-Neukalibrierung, Party-Modus Endlage=Startlage.
2026-07-04 Spec-Korrektur: C reklassifiziert (Touch-Kalibrierung statt Code-Bug), B auf timestamp fokussiert
    Diagnose-Zurueck-Button nutzt behandelte Aktion menu_2 -> kein Code-Bug;
    schlechte Treffbarkeit = Touch-Versatz am unteren Bildschirmrand -> geht in E auf.
    Zeitzonen-Fix auf SecurityEvent.timestamp begrenzt (last_seen nicht im UI angezeigt).
2026-07-04 fix(motor): T1 Motor-Pinsaetze L<->R (main.py) committen (war uncommitted, ging bei reset verloren)
    Am realen Aufbau fuhr die alte Zuordnung rueckwaerts+spiegelverkehrt;
    LEFT=13/8/9, RIGHT=10/11/12. Verifiziert per Referenz-Linienlauf.
    [main.py]
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2026-07-07 feat(touchpanel): Datum/Adresse aktualisiert + Flicker-Fix + Fuellstand-Overlay
    - Datum 15.07.2026 und Adresse "Luebecker Ring 2" als RLE-Overlays
    - Teil-Redraw statt Voll-Reblit pro set_status -> kein Flackern mehr
    - Fuellstand-Overlay nur bei relevanter Aenderung neu zeichnen
    [ui.py]
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2026-07-07 fix(fill): Fuellstand halten-mit-Hysterese statt Perzentil-Fenster
    Perzentil-/Median-Fenster war von der US-Trefferquote abhaengig: bei
    niedrigem Fuellstand (Inhalt tiefer -> Ping trifft seltener) fiel der Wert
    wieder faelschlich auf 0. Jetzt trefferquoten-unabhaengig:
    - eine mehrfach bestaetigte Oberflaeche wird gehalten (min_confirm_hits
    ueber einen Nah-Puffer -> einzelne Nah-Ausreisser fallen raus)
    - jeder Nah-Treffer setzt den Leer-Zaehler zurueck
    - erst nach empty_confirm_reads Fern-Messungen in Folge OHNE jeden
    Nah-Treffer faellt der Wert auf 0 (leere Tonne -> ~2-3 s)
    Verifiziert: haelt ~37 % stabil (0 Faelsch-0 in 20 s) statt 6/13 vorher.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
2026-07-11 fix(pico): Pin-Belegung an Post-Blast-Verkabelung + Wende 47000 + Obstacle-Entprellung
    - main.py: Motor-Pins auf die nach Verpol-Blast/Treibertausch neu verkabelte
    und per Einzelmotor-Test verifizierte Belegung: LINKS=10/11/12 (fwd=0),
    RECHTS=13/8/9 (fwd=1). Ersetzt die T1-Belegung (passte zur alten Verkabelung).
    - global_controller_test.py: 180deg-Wende 44000 -> 47000 Schritte (Home+Street).
    - global_controller_test.py: Front-Hinderniserkennung entprellt
    (_confirm_front_obstacle): Stopp erst bei >=2/3 bestaetigenden Messungen ->
    keine Fehl-Stopps durch einzelne spurious Kurzechos im Fahrbetrieb.
    Auf dem Pico geflasht + sauberer Boot/Bridge-Connect verifiziert.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
    [main.py]
2026-07-11 fix(bridge): genau eine aktive Pico-Verbindung -> Kommando-Queue blockiert nicht mehr
    Der Pico reconnectet bei WLAN-Hickups am Nano-Router, ohne dass die alte TCP-
    Verbindung sofort als tot erkannt wird. Folge: mehrere handle_client/Poll-Tasks
    parallel, die sich sent_command_ids teilen und Kommandos in halb-offene Sockets
    schrieben -> der echte Pico bekam sie nie, kein ACK, das unbestaetigte Kommando
    blockierte die FIFO-Queue (alle Web-App-Befehle danach kamen nicht mehr an).
    Fix: bei neuer Verbindung die alte hart schliessen + deren Poll-Task canceln
    (_active_writer/_active_poll_task). So gibt es genau eine aktive Verbindung und
    Kommandos gehen nur an den aktuellen Socket.
    Verifiziert: st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
2026-07-11 tune(pico): Linienfahrt fuer schwaches Drehmoment + Wende invertiert
    Nach Debugging am realen Aufbau (Sensor/Position/PD/Speed live verifiziert):
    - Pin-Belegung final: LINKS=13/8/9 (fwd=0), RECHTS=10/11/12 (fwd=1); PD-Vorzeichen
    per Motor-/Sensor-Test bestaetigt (left=base-corr, right=base+corr).
    - Geradeausfahrt + Korrektur funktionieren (Position haelt 0, regelt sauber).
    - Tempo gedrosselt fuer Drehmoment unter Last: base_speed 80->45, max_freq
    7000->4000, max_speed 60, speed_curve 25, kp 28, max_correction 40.
    - min_speed 0->20: inneres Rad stoppt nicht mehr ganz -> kein harter Pivot-Stall
    (Tonne kurvt statt zu pivotieren, verliert die Linie nicht mehr auf Geraden).
    - Wende (home +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
    [main.py]
2026-09-06 fix(pd): Regler-Vorzeichen final auf +/- gedreht (live am Aufbau verifiziert)
    left_speed = base_speed + correction, right_speed = base_speed - correction.
    Mehrfach live gegengeprueft: Position lief in wiederholten Hands-off-Fahrten
    sauber von Extremwerten (z.B. +1.5) auf 0 zurueck, nicht davon weg. Vorherige
    Team-Empfehlung (-/+) beruhte auf Tests bei zu geringem Sensor-Kontrast und
    war durch die dort unzuverlaessigen Sensordaten nicht belastbar.
    [PDcontroller.py]
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2026-09-11 fix(pico): Endmarkierung ab 4 aktiven Sensoren (Sensor C4 defekt)
    Liniensensor bekommt den Parameter end_marker_min_active; main.py setzt ihn
    auf 4, weil der Sensor an C4 abgeklemmt ist und dauerhaft 0 liest (am
    2026-07-11 per MUX-Pulltest verifiziert). Ohne die Aenderung wuerde die
    Endmarkierung nie erkannt. Bei repariertem Sensor wieder entfernen.
    [main.py]
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2026-09-11 chore: Vorgaengerprojekt (Alt/) aus dem Abgabestand entfernen
    STL-Dateien, Teileliste, Schaltplan, alter Client- und Servercode sowie
    Dokumentation und Praesentation der Smarten Muelltonne 1.0. Bleiben in der
    Historie erreichbar (zuletzt in dae74ec9).
    [Abdeckung.stl, Anzeige.stl-neu.stl, Deckel Anzeige neu.stl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]
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
